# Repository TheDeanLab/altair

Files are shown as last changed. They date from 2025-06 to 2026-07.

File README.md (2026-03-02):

<h1 align="center">
altair

altair

<h3 align="center">
	Cost-Effective, Open-Source, Light-Sheet Microscopy Solutions for Subcellular Imaging.
</h3>
</h1>





**Altair** aims to democratize high-resolution light-sheet fluorescence microscopy. By combining **modular optomechanics**, **cutting-edge lens simulations**, and **intelligent software**, **Altair** enables the rapid assembly of high-performance light-sheet microscopes in a user-friendly package.

As reported in our eLife publication, Altair-LSFM is a high-resolution, sample-scanning light-sheet microscope that uses an in-silico optimized optical train and a custom-machined baseplate to simplify alignment. In bead-based benchmarking, Altair-LSFM achieved average FWHM values of 328 nm (x), 330 nm (y), and 464 nm (z) before deconvolution, improving to 235.5 nm (x), 233.5 nm (y), and 350.4 nm (z) after deconvolution across a 266 µm field of view.

## Publication

- Haug J, Galecki S, Lin H-Y, Wang X, Dean KM. *A high-resolution, easy-to-build light-sheet microscope for subcellular imaging.* eLife. 2025;14:RP106910. [https://doi.org/10.7554/eLife.106910](https://doi.org/10.7554/eLife.106910)

## Motivation

Cellular behavior is orchestrated by diverse signaling mechanisms that often hinge on **molecular events precisely organized in space and time**. These events include rapid, localized protein interactions that drive processes such as cell division, migration, and differentiation. **Altair** addresses the need for **high-resolution live-cell imaging**, empowering researchers to:

- Visualize spatially regulated processes.
- Collect quantitative 3D time-lapse data.
- Bridge molecular probe design and advanced computational image analysis.

## Goal

The overarching goal is to provide a **modular, cost-effective 3D light-sheet microscope** that:
- Can be assembled with minimal prior optics expertise.
- Delivers ~235 nm lateral and ~350 nm axial resolution after deconvolution (~328/330 nm in XY and ~464 nm in Z before deconvolution) across a 266 µm field of view.
- Seamlessly integrates with our user-friendly, **intelligent imaging software** [navigate](https://github.com/TheDeanLab/navigate).
- Streamlines data acquisition, drastically reducing barriers to cutting-edge microscopy.

## Key Features

1. **High-Resolution Optics**  
   - Optical designs extensively **simulated in Ansys Zemax OpticStudio** to ensure robust performance across the visible spectrum.
   - Thorough **tolerance analysis** to maintain alignment and resolution in non-specialist environments.

2. **Rugged Mechanical Design**  
   - **Computer-aided design (CAD) with Autodesk Inventor** for stress testing and mechanical reliability.
   - **Xometry** manufacturing ensures precision component fabrication.
   - **Dowel pins** and **Thorlabs Polaris mounts** allow reproducible alignment of optical elements.

3. **Easy-to-Source Components**  
   - Optics primarily sourced from **Thorlabs**, with **Polaris mounts** for stable positioning.
   - Motion control solutions (X, Y, Z, focus, sample scanning) from **Applied Scientific Instrumentation**.
   - Open-hardware ethos with minimal custom parts to reduce cost and wait times.
   - Detailed step-by-step assembly instructions.

4. **Intuitive Control Software**  
   - Built to interface seamlessly with [navigate](https://github.com/TheDeanLab/navigate).
   - Automated routines for calibration, 3D volume acquisition, and intelligent imaging.

## Getting Started

- **Review the [Documentation](https://thedeanlab.github.io/altair/)**
- **Procure Hardware**
- **Download and Install** [navigate](https://github.com/TheDeanLab/navigate)
- **Assemble Hardware**
- **Optimize Alignment**
- **Validate Performance**

## Authors

- John Haug, Ph.D.
- Kevin M. Dean, Ph.D.

## Funding

- **UTSW-UNC Center for Cell Signaling Analysis** NIH NIGMS RM1GM145399
- **Center for Metastatic Tumor Imaging** NIH NCI U54CA268072

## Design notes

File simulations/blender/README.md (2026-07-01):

# Blender Optics Simulations

This directory contains Blender Python source for educational Altair optics
alignment videos.

The scripts build Blender scenes programmatically. The Python source is the
source of truth; generated `.blend` files and rendered movies are build
artifacts.

## First Scene

`scenes/achromat_back_reflection.py` generates a teaching scene for aligning a
mounted achromatic doublet with a narrow collimated 561 nm laser beam. The beam
passes through a small aperture in a business card, reaches the lens, and two
back-reflection spots return to the card. The animation shows separate
ray-traced alignment states: rotation correction moves both spots together,
horizontal translation splits and recenters the spots left/right, vertical
translation splits and recenters the spots up/down, and final alignment centers
both return spots on the aperture.

The model is intentionally hybrid: it is geometrically plausible and uses
teaching-scale dimensions, but it exaggerates small alignment errors so the
motion is legible in video. The lens is represented as an AC254-100-A-style
cemented doublet with separate N-BK7 and SF5 elements, a curved cemented
interface, a weakly curved rear surface, and an LMR1-style fixed mount. Return
spots are computed from geometric ray-bundle reflections and therefore have
surface-dependent positions and diameters.

The scene includes three camera views: a wide setup view, a close-up view of the
card aperture and return spots, and a slow hero camera move for a polished
single-view movie. Minimal in-scene labels identify the aperture card, doublet,
mount, and two return reflections without adding narration or external editing.

## Walking-Beam Scene

`scenes/walking_beam_alignment.py` generates a teaching scene for walking a
laser beam with two steering mirrors and two irises. The scene uses an
import-safe finite-aperture ray trace from the source through M1, M2, Iris 1,
and Iris 2. Beam segments, mirror footprints, iris spots, blocking/clipping
state, and mirror display rotations are derived from that trace.
Animated beam segments are rendered as endpoint-keyframed curve objects, not
Euler-rotated cylinders, so the visible beam remains constrained by the traced
start and end points between storyboard samples.

The tutorial sequence starts misaligned, uses M1 to center the near iris, uses
M2 to center the far iris, then alternates through two refinements until both
irises are centered. Rendered views include wide, iris close-up, hero, top-down,
and stacked diagnostics. The top-down view is particularly useful for checking
that the folded M1-to-M2 path is continuous and that the post-M2 direction is
unambiguous.

## Fidelity Notes

`altair_blender/prescriptions.py` stores the source-backed model constants. The
mounted AC254-100-A-ML dimensions and LMR1/M mount dimensions come from Thorlabs
drawings. The AC-series surface prescription is used for the educational
geometric model so the rendered doublet and reflected spots respond to surface
curvature.

The spot animation traces reflected ray bundles from selected spherical
surfaces back to the card plane. The optics helpers also include a sequential
geometric tracer that branches rays into reflected and transmitted paths through
all modeled achromat surfaces. The model does not yet include wavelength-
dependent coating reflectance, polarization, diffraction at the aperture, or
Gaussian beam propagation. Spot positions and diameters are physically
motivated, then visually scaled for legibility.

## Run

From the repository root:

```bash
blender --background --python simulations/blender/scenes/achromat_back_reflection.py
```

To save a generated Blender file, pass a path after `--`:

```bash
blender --background --python simulations/blender/scenes/achromat_back_reflection.py -- output/achromat_back_reflection.blend
```

The output directory must already exist.

## Render Movies

Use the render script to create the `.blend` file, wide/card/hero PNG
sequences, wide/card/hero MP4 movies, a vertically stacked wide-plus-card PNG
sequence, and a stacked MP4 movie:

```bash
simulations/blender/scripts/render_achromat_back_reflection.sh
```

The default render mode is `final`, which applies the Cycles beauty preset. Use
`--draft` for fast card-only timing checks, or `--preview` /
`RENDER_MODE=preview` for full-pipeline EEVEE iteration.

For a fast draft render that only writes the card close-up movie at lower
resolution with frame stepping:

```bash
simulations/blender/scripts/render_achromat_back_reflection.sh --draft output/draft
```

By default, outputs are written under `output/achromat_back_reflection/`:

```text
achromat_back_reflection.blend
frames/wide/frame_0001.png ...
frames/card_closeup/frame_0001.png ...
frames/hero/frame_0001.png ...
frames/stacked/frame_0001.png ...
achromat_back_reflection_wide.mp4
achromat_back_reflection_card_closeup.mp4
achromat_back_reflection_hero.mp4
achromat_back_reflection_stacked.mp4
```

For a faster smoke render, override the frame range and resolution:

```bash
FRAME_START=1 FRAME_END=24 RESOLUTION_X=960 RESOLUTION_Y=540 \
  simulations/blender/scripts/render_achromat_back_reflection.sh --preview output/smoke
```

Run a dry-run plan without invoking Blender or `ffmpeg`:

```bash
simulations/blender/scripts/render_achromat_back_reflection.sh --dry-run
simulations/blender/scripts/render_achromat_back_reflection.sh --draft --dry-run
simulations/blender/scripts/render_achromat_back_reflection.sh --preview --dry-run
```

Render the walking-beam scene with:

```bash
simulations/blender/scripts/render_walking_beam_alignment.sh
```

For key-frame still review:

```bash
simulations/blender/scripts/render_walking_beam_alignment_stills.sh --draft --frame 72 output/walking-beam-frame-72
```

## Test

Run non-Blender checks from the repository root:

```bash
uv run pytest tests/test_blender_optics_math.py tests/test_blender_import_contracts.py tests/test_blender_endpoint_beams.py tests/test_achromat_scene_contract.py tests/test_blender_render_script.py tests/test_walking_beam_physics.py tests/test_walking_beam_scene_contract.py tests/test_walking_beam_render_script.py
```

If `uv run` is not suitable in the local environment, use:

```bash
pytest tests/test_blender_optics_math.py tests/test_blender_import_contracts.py tests/test_blender_endpoint_beams.py tests/test_achromat_scene_contract.py tests/test_blender_render_script.py tests/test_walking_beam_physics.py tests/test_walking_beam_scene_contract.py tests/test_walking_beam_render_script.py
```

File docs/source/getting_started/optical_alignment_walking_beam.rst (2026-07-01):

.. _optical_alignment_walking_beam:

#################################
Walking A Beam Through Two Irises
#################################

Goal
====

The goal is to make a laser beam pass through the centers of two same-height
irises after two steering mirrors. The first iris defines the near point on the
desired optical axis. The second iris defines the far point. When the beam is
centered on both irises, the beam position and angle match the line selected by
those two apertures.

This is a geometric alignment method. It does not require the downstream optic
to be installed yet, which makes it useful when setting beam height, preparing a
beam expander path, or establishing a clean reference line across an optical
table.

.. card:: Walking-Beam Alignment Simulation

   This simulation shows a Z-fold made from two kinematic mirror mounts and two
   same-height irises on a 25.4 mm table-hole row. The wide view shows the two
   mirrors walking the beam onto the iris row. The close-up view shows the near
   and far iris readouts during each correction. The top-down panel shows why
   the method controls both lateral beam position and propagation angle.

   .. raw:: html

      <video controls preload="metadata" style="width:100%;">
        <source src="../_static/optical_alignment/videos/walking_beam_alignment_stacked.mp4" type="video/mp4">
        Your browser does not support embedded video.
      </video>

   `Download the walking-beam alignment movie <../_static/optical_alignment/videos/walking_beam_alignment_stacked.mp4>`_

   The top-down view is useful when checking whether the beam path remains
   continuous from mirror to mirror and then through both irises.

   .. raw:: html

      <video controls preload="metadata" style="width:100%;">
        <source src="../_static/optical_alignment/videos/walking_beam_alignment_top_down.mp4" type="video/mp4">
        Your browser does not support embedded video.
      </video>

   `Download the top-down walking-beam movie <../_static/optical_alignment/videos/walking_beam_alignment_top_down.mp4>`_

Why This Works
==============

A straight beam is fully specified by two points. Two irises therefore define
the desired path: the beam must pass through the first aperture and then through
the second aperture without clipping.

The two mirrors provide two coupled controls. A first-mirror adjustment changes
where the beam lands at the near iris and also changes the downstream angle. A
second-mirror adjustment changes the downstream angle and therefore moves the
far iris spot strongly. Because the controls are coupled, a single pass is
rarely perfect. Alternating between the near iris and the far iris converges on
the line through both aperture centers.

Use small iris openings only after rough alignment is close. Starting with a
larger opening prevents accidental clipping and makes it easier to see which
mirror adjustment is moving the beam in the intended direction.

Setup Geometry
==============

Use a low-power visible alignment beam, wear appropriate laser safety eyewear,
and place beam blocks wherever the rough beam or mirror reflections could leave
the intended table path.

Place Iris 1 as close as reasonably possible to the second steering mirror. This
near iris gives a sensitive readout of the beam position just after the mirror
pair. Place Iris 2 farther downstream on the same desired path. A longer
distance between the two irises makes angular error easier to see, so the final
alignment is more accurate when the far iris is placed farther away.

A table-hole row is a convenient reference for a straight horizontal path. When
using the holes as a geometric reference, place each mirror so that the mirror
surface is centered on the intended turning point of the hole pattern. The
outside of the mirror mount is not the optical reference; the reflective surface
is.

Before beginning, set the mirror actuators near the middle of their travel.
This leaves adjustment range in both directions. Also center the beam on both
mirror surfaces during rough placement. If the beam starts near an edge of a
mirror, later corrections can clip the beam or force the actuator to the end of
its range.

Right-angle reflections are convenient because they make the geometry easy to
read on a rectangular optical table, but they are not required. Two steering
mirrors are sufficient to laterally translate a beam onto a new parallel path.

Step-By-Step Protocol
=====================

1. Set both irises to the same height and place them on the desired beam path.
   Put Iris 1 close to Mirror 2 and Iris 2 farther downstream on the same
   reference line.

2. Open both irises enough that the rough beam can be found safely without
   clipping.

3. Place two steering mirrors before the first iris. Start with the mirror
   actuators near mid-travel, the beam centered on both mirror faces, and the
   reflective surfaces located on the intended table-hole turning points.

4. Roughly steer the beam so that it reaches the first iris and continues toward
   the second iris.

5. Adjust the first mirror to center the near iris. Watch the beam spot at
   Iris 1 and use small, deliberate mirror motions.

6. Adjust the second mirror to center the far iris. Watch the beam spot at
   Iris 2 and bring it to the same-height aperture center.

7. Return to the first mirror and re-center Iris 1. The second-mirror change
   usually perturbs the near iris slightly.

8. Return to the second mirror and re-center Iris 2.

9. Iterate until both iris spots stay centered after each correction.

10. Reduce the iris openings and repeat the final corrections. Stop when the
    beam passes cleanly through both apertures at the working aperture size.

Troubleshooting
===============

If Iris 1 centers but Iris 2 moves far away, the mirror corrections are too
large or the initial Z-fold geometry is too coarse. Open the far iris, make a
rough second-mirror correction, and then restart with smaller movements.

If Iris 2 centers but Iris 1 no longer transmits, return to the first mirror.
This is the normal coupling between the two controls, not a sign that the
method failed.

If the beam clips both irises at different heights, recheck the mechanical
height of the iris centers before continuing. Walking the beam cannot fix a
reference line defined by apertures at different heights.

If the beam shape changes or becomes crescent-shaped at an iris, the beam is
clipping. Open the iris, recover a full round spot, and only then close the
aperture again.

If a mirror actuator runs out of range, do not keep forcing the correction with
the knob. Recenter the actuator, reposition the mirror mount so the beam is
again near the center of the mirror, and restart the rough alignment.

If the beam is centered on both irises but walks across a mirror surface, the
mechanical layout is probably not centered on the intended turning points. Move
the mount so the reflective surface, not the mount body, coincides with the
reference geometry, then repeat the alignment.

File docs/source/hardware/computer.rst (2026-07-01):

.. _computer-home:

###############################
Acquisition Computer
###############################

Modern scientific cameras are capable of capturing images at very high frame rates.
For example, the Orca-Lightning from Hamamatsu, when imaging a region of interest of
4608 × 128, can image at 2203 frames per second, totaling 1.3 terapixels per second. It
is important to have a computer that can handle this data rate. For many applications, we recommend Colfax International's SXP9000 workstation, which
includes several convenient features, including:

-   A large number of high-speed peripheral slots. While originally designed to host
    GPU cards, these slots can be used for other high-speed peripherals, such as frame
    grabbers.
-   A high-speed NVMe SSD, which can achieve upwards of 20 GB/s under ideal
    conditions.
-   10 GbE LAN - 10 G Ethernet or faster, if supported by your institution, is highly
    recommended for transferring data to and from the computer. This computer provides
    this high-speed connection without necessitating an additional network card, freeing
    up precious space in the computer.
-   USB-C ports that can be used for image display, keyboard, and mouse. Again, by
    eliminating the need for a graphics card, more space is available to other
    peripheral devices.
-   Redundant power supplies - in the event of a power supply failure, the computer will
    continue to operate. Moreover, they will be able to drive some of the more power-hungry
    components, such as frame grabbers.
-   Aggressive cooling - the computer is designed to handle the heat generated by the
    high-speed components.

---------------

Standard Specifications
_______________________

A general build for an imaging computer is as follows:

-   Windows 10 Pro. This is the most common operating system for scientific imaging
    applications.
-   2 × Intel Xeon Silver CPUs, for a total of 16 cores/32 threads at 3.2 GHz. Higher speeds
    and a greater number of cores are advantageous but expensive.
-   128 GB of 3200 MHz DDR4 RAM. This is more than sufficient for most applications.
-   800 GB M.2 NVMe SSD. Used to host and run the operating system.
-   20 TB 7200 RPM SATA HDD. Used as a 'cold storage' for long-term data storage.
-   NVIDIA T1000 Video Card. This is a low-end video card that can be used to drive
    displays and perform some basic image processing. The priority for this computer
    is driving the microscope and acquiring data, so a high-end video card is not necessary.
-   Intel X710-T2L 10 GbE card. If the motherboard does not provide 10 GbE, this card can
    be used to provide high-speed network connectivity.
-   7.68 TB NVMe SSD. Used as the primary data drive.

.. note::

    Recently, Hamamatsu released a Linux driver for their cameras. Linux
    provides several advantages to Windows-based operating systems, including read
    and write operations with lower overhead. This is especially important for next-generation
    file formats, such as N5, OME-Zarr, and Zarr, all of which break large
    images up into smaller 'chunks' that can be read and written independently. To
    learn more, we recommend reading
    `Moore et al. 2021 <https://pubmed.ncbi.nlm.nih.gov/34845388/>`_, and
    `Moore et al. 2023 <https://pubmed.ncbi.nlm.nih.gov/37428210/>`_.

-------------

Configuring Power Management Settings
_____________________________________

On modern platforms, the *computer's* power management configuration (Windows power plan, chipset/firmware drivers, and BIOS/UEFI power features) can materially affect throughput, latency, and run-to-run stability. By properly configuring the computer, navigate will operate more deterministically and at higher performance. Below is a step-by-step guide to optimize these settings.

Protocol: Windows configuration
------------------------------------

1. Update baseline software and firmware
^^^^^^^^^^^^^^^^^^^^^^^^^^^^^^^^^^^^^^^^

#. Ensure the system is on a supported Windows release (Windows 10/11 or Windows Server).
#. Apply your vendor's recommended BIOS/BMC/firmware updates (Supermicro/HPE/Dell/etc.).
#. Reboot after firmware updates.

2. Set Windows to a performance-focused power mode
^^^^^^^^^^^^^^^^^^^^^^^^^^^^^^^^^^^^^^^^^^^^^^^^^^

**General Power Settings** - We recommend setting Windows to a performance-oriented power plan to minimize power-saving features that can impact performance. This includes the high performance plan or, where available, the ultimate performance plan. To change these settings via the GUI, navigate to:
Control Panel → Power Options → select **High performance** (or **Ultimate Performance**).

**Minimum Processor Settings** - Additionally, adjust the processor power management settings to ensure the CPU operates at full performance when plugged in. Set both the minimum and maximum processor states to 100% and disable PCI Express Link State Power Management. This can be done via:
Control Panel → Power Options → Change plan settings → Advanced power settings:

3. Install chipset platform drivers (including Intel Management Engine)
^^^^^^^^^^^^^^^^^^^^^^^^^^^^^^^^^^^^^^^^^^^^^^^^^^^^^^^^^^^^^^^^^^^^^^^

The Intel Management Engine (ME) provides platform management
capabilities independent of the OS. Install the latest ME drivers from your
motherboard or system vendor's support page.

#. Install your **vendor chipset driver bundle** (preferred for servers/workstations).
#. Install the **Intel Management Engine Interface (MEI)** driver package (vendor-supplied).
#. Reboot.

**Confirm MEI is installed:**
Device Manager → System devices → look for **Intel(R) Management Engine Interface**.

4. Optional Windows Update: CPU/chipset-related driver updates
^^^^^^^^^^^^^^^^^^^^^^^^^^^^^^^^^^^^^^^^^^^^^^^^^^^^^^^^^^^^^^

Windows can deliver additional driver updates through **Optional updates**.

Settings → Windows Update → Advanced options → Optional updates → Driver updates

Protocol: BIOS/UEFI configuration
---------------------------------

The exact BIOS menu paths vary by vendor and CPU generation, but the concepts are consistent.

1. NUMA and Node Interleaving
^^^^^^^^^^^^^^^^^^^^^^^^^^^^^

* **Disable Node Interleaving** (recommended for modern NUMA-aware OSes).
  When enabled, firmware interleaves memory across sockets and presents a UMA-like view,
  which typically reduces NUMA locality benefits.

.. important::
   Some platforms do not expose an explicit **Node Interleaving** toggle (or it is hidden
   when the platform defaults to NUMA mode). In that case, verify NUMA is active in the OS
   (multiple NUMA nodes visible) and proceed with the remaining power settings.

2. Power and idle-state controls (C-states, P-states)
^^^^^^^^^^^^^^^^^^^^^^^^^^^^^^^^^^^^^^^^^^^^^^^^^^^^^

These settings are commonly found under:

Advanced → Advanced CPU Configuration → Advanced Power Management Configuration

The intent is:

* Keep **Turbo + P-states enabled** (fast frequency scaling).
* Disable **deep core/package C-states** (avoid wake-up latency and jitter).
* Disable **autonomous hardware power management** (keep behavior deterministic).

Recommended BIOS settings (with 1-line descriptions)
----------------------------------------------------

.. list-table:: BIOS settings reference (performance mode)
   :header-rows: 1
   :widths: 28 18 54

   * - Setting (location)
     - Recommended
     - What it does (1 line)
   * - **CPU P State Control** (APM)
     -
     -
   * - AVX P1
     - Nominal
     - Controls the target performance state under heavy AVX; *Nominal* avoids extra down-binning beyond platform defaults.
   * - SpeedStep (P-states)
     - Enabled
     - Enables OS-managed frequency/voltage scaling (fast ramp-up without sleeping).
   * - EIST PSD Function
     - HW_ALL
     - Uses hardware assistance for P-state transitions across all cores for responsiveness.
   * - Turbo Mode
     - Enabled
     - Allows boosting above base frequency when power/thermals permit.
   * - **Hardware PM State Control** (APM)
     -
     -
   * - Hardware P-States (HWP)
     - Disabled
     - Prevents the CPU from autonomously selecting performance states (keeps policy deterministic).
   * - Autonomous PM
     - Disabled
     - Disables out-of-band autonomous power decisions that can introduce variability.
   * - **CPU C State Control** (APM)
     -
     -
   * - Enable Monitor MWAIT
     - Disabled
     - Disables MWAIT-based idle entry hints that can lead to deeper idle behavior.
   * - CPU C1 Auto Demotion
     - Disabled
     - Prevents automatic demotion from shallow idle (C1) into deeper C-states.
   * - CPU C6 Report
     - Disabled
     - Hides C6 from the OS, preventing deep core sleep selection.
   * - Enhanced Halt State (C1E)
     - Disabled
     - Disables C1E voltage/frequency drop behavior that can add wake latency/jitter.
   * - **Package C State Control** (APM)
     -
     -
   * - Package C State
     - Disabled
     - Prevents the entire socket/package from entering deep idle (high wake latency).
   * - Package C State Limit
     - C0/C1
     - Caps package idle to shallow states only (best for consistent multi-socket performance).

References
----------

* `Microsoft powercfg documentation <https://learn.microsoft.com/en-us/windows-hardware/design/device-experiences/powercfg-command-line-options>`_
* `Recommended hardware drivers <https://support.microsoft.com/en-us/windows/automatically-get-recommended-and-updated-hardware-drivers-0549a8d9-4842-8acb-75fa-a6faadb62507>`_
* `Windows power and performance tuning <https://learn.microsoft.com/en-us/windows-server/administration/performance-tuning/hardware/power/power-performance-tuning>`_
* `Understanding automatic and optional updates <https://learn.microsoft.com/en-us/windows-hardware/drivers/dashboard/understanding-windows-update-automatic-and-optional-rules-for-driver-distribution>`_
* Intel Management Engine resources (vendor support pages)
* `C-state guidance - Part 1 <https://edc.intel.com/content/www/us/en/design/products/ethernet/appnote-perf-tuning-guide-700-series-linux/%E2%80%8Bc-state-control/>`_
* Cisco UCS BIOS tuning guides (vendor support pages)

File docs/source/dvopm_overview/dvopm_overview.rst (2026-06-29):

.. _dvopmoverview-home:

##############################
Introduction
##############################

Direct-View OPM
_______________

Direct-View Oblique Plane Microscopy (dvOPM) is an oblique-plane light-sheet microscopy technique designed for mesoscopic fluorescence imaging of extended specimens. In this approach, an oblique imaging plane within the sample is optically sectioned using a light sheet and directly projected onto a camera sensor.

Conventional oblique-plane microscopy systems typically rely on a tertiary imaging objective to re-image the tilted plane onto the detector. In contrast, dvOPM eliminates this requirement by forming the remote image directly on the camera sensor using a simplified relay. This reduces optical complexity and system footprint while preserving the optical sectioning capability of light-sheet microscopy.

As a result, dvOPM enables imaging over large fields of view with optical sectioning in a compact and accessible optical configuration.

------------------------------

System Architecture
___________________

A typical dvOPM system consists of separate illumination and detection optical paths arranged around a shared sample region. The illumination path generates an oblique light sheet that intersects the specimen, while the detection path collects fluorescence from the illuminated plane and relays the tilted image onto a camera sensor.

In general implementations, the detection path is formed using microscope objectives and relay optics, often requiring multiple objectives to re-image the oblique plane. The illumination path is typically implemented separately from the detection optics, particularly when using low numerical aperture objectives that do not support integrated light-sheet delivery. The system is commonly operated in a stage-scanning configuration, where the sample is translated through the stationary illumination and detection planes to acquire volumetric data.

The Altair dvOPM presented here follows this overall architecture while implementing a specific realization of the system as described below.

The detection subsystem is implemented as a remote-imaging relay using a pair of photographic lenses with external pupils. An emission filter wheel (FW1000, Applied Scientific Instrumentation) is positioned within the relay to enable fluorescence imaging. The image is formed directly onto a compact camera (Ximea MU196MR-ON) with a pixel size of 1.4 µm. The entire detection assembly is mounted on a modular baseplate and attached to a motorized linear translation stage, allowing the detection train to be positioned relative to the specimen.

The illumination subsystem is implemented as a separate optical train. It begins with a Powell lens, followed by a sequence of three achromatic doublets that relay and shape the beam. A resonant galvo is incorporated within the illumination path, and the resulting beam forms a micron-scale light sheet that is launched obliquely into the specimen.

The system operates in a stage-scanning geometry, where the sample is translated through the stationary illumination and detection planes. The illumination and detection subsystems are mounted as independent modular baseplates on the optical table, while the stage is positioned above them.

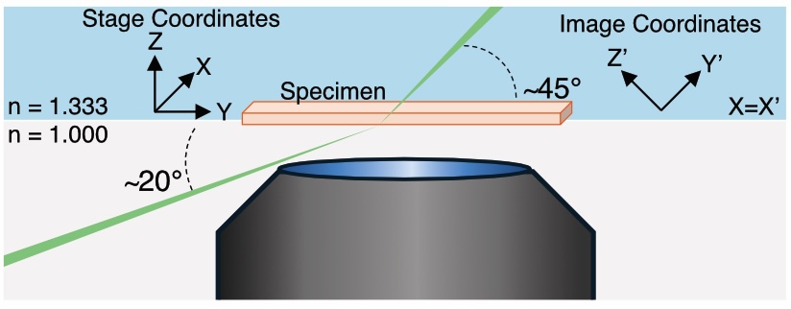
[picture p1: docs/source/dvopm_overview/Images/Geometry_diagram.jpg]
Schematic of the Altair DV-OPM system.


    **Figure 1:** Schematic Geometry of the Altair DV-OPM system. 

The above the schematic illustrates the optical geometry of the system, showing the relative arrangement of the illumination and detection paths around the sample region and the axes defining the oblqiue plane and the stage coordinates.
The illumination light-sheet is launched externally through the coverslip at an angle of approximately 20◦ and refracts to approximately 45◦ upon entering the aqueous specimen. Fluorescence from the obliquely illuminated plane is collected in the epi-direction by the photographic-lens-based detection path. Unprimed axes denote the stage coordinate system, in which Y is the sample-scanning direction, Z is the specimen-depth direction and X is parallel to the long axis of the light-sheet. Primed axes denote the oblique image coordinate system recorded by the camera, in which Y′ is the light-sheet propagation direction, X′ is the long
axis of the light-sheet and Z′ defines the light-sheet thickness. The stage X axis corresponds to the image X′ axis. Thus, each camera frame captures an X′Y′ oblique plane, while volumetric imaging is performed by translating the specimen along stage Y . Following acquisition, image stacks are computationally sheared and rotated into the stage coordinate frame for visualization. 

------------------------------

The detailed optical design and implementation of the detection and illumination subsystems are described in the following section.

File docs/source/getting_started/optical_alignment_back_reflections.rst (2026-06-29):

.. _optical_alignment_back_reflections:

#########################
Back-Reflection Alignment
#########################

The goal is to make the optic normal to the incoming beam and centered on the
beam path. A simple aperture card lets you see light that reflects from the
optic and returns toward the source. When the useful back-reflection spots are
centered on the aperture, the optic is close to normal incidence and centered
well enough to continue the alignment.

This method is useful because it gives a fast, sensitive readout before moving
to more complicated system-specific alignment steps. It does not replace later
checks of beam height, beam walk, collimation, or image quality, but it helps
establish a clean starting condition for each optic.

.. card:: Achromat Back-Reflection Simulation

   This simulation shows a collimated 561 nm alignment beam passing through a
   small aperture in a card, reflecting from an achromatic doublet, and returning
   two spots to the card. The top view shows the physical layout. The lower view
   shows the aperture-card readout as tilt and position are corrected.

   .. raw:: html

      <video controls preload="metadata" style="width:100%;">
        <source src="../_static/baseplate2_alignment/alignment/videos/achromat_back_reflection_stacked.mp4" type="video/mp4">
        Your browser does not support embedded video.
      </video>

   `Download the alignment movie <../_static/baseplate2_alignment/alignment/videos/achromat_back_reflection_stacked.mp4>`_

Why This Works
==============

When a lens is placed in a laser beam, a small amount of light reflects from
each optical surface. For a simple lens or achromat, the most visible returns
often come from the front and rear surfaces. These returns appear as distinct
spots on the card.

Flat or nearly plano surfaces return a crisp, collimated spot that is roughly
the same diameter as the incoming alignment beam. Spherical or curved surfaces
can return spots that expand or focus, depending on the curvature of the surface
and the distance back to the card. In compound optics, the different surfaces
can therefore produce spots with different sizes.

The card gives those returns a visible target. The aperture marks the incident
beam position. If a return spot lands on the aperture, that reflected ray bundle
is traveling back along the incident beam path.

Setup
=====

Use a visible, low-power, collimated alignment beam. A 561 nm beam is convenient
when it is available, but the same geometry applies to other visible alignment
wavelengths. Keep the beam power low, use proper laser safety practices, and
avoid looking directly into any specular reflection.

Place a target card with a small aperture in the beam before the optic. A
business card with a narrow aperture works well because it blocks enough light
to reveal the return spots while still allowing the incident beam to pass. The
aperture must be centered on the true beam path before the optic is inserted.
If the aperture is not centered, the card itself biases the measurement.

Mount the optic downstream of the card. Keep enough space between the card and
optic for the return spots to separate visibly, but not so much space that weak
reflections become hard to see.

Interpreting The Reflection Spots
=================================

If the beam is not centered on the optic, the back reflections will be displaced
on the card. Lateral displacement of the optic moves the return spots laterally.
Vertical displacement also moves the return spots on the card because the card
records the beam position in its transverse plane.

When the beam is normal to the optic, the useful return spots should move in a
symmetrical way as the optic is centered. If the optic is tilted relative to the
laser propagation direction, the return spots will not be displaced
symmetrically. This asymmetry is the key sign that angle must be corrected
before position can be trusted.

The aperture card is part of the measurement. A shifted, tilted, damaged, or
poorly sized aperture can make a good optic alignment look bad, or make a bad
alignment look better than it is. Recheck the aperture position whenever the
beam path or card position changes.

Step-By-Step Protocol
=====================

1. Establish a clean, collimated alignment beam at the desired beam height.

2. Place the aperture card upstream of the optic location.

3. Center the aperture on the incident beam. The beam should pass cleanly
   through the aperture without clipping.

4. Insert the optic in its mount downstream of the card.

5. Observe the return spots on the card. For an achromat, expect more than one
   visible return, and expect the spots to have different diameters.

6. Correct angular alignment first. Adjust tip and tilt until the useful return
   spots move symmetrically toward the aperture.

7. Correct lateral and vertical position. Translate the optic until the useful
   return spots are centered on the aperture.

8. Iterate angle and position adjustments. These degrees of freedom are coupled,
   so one pass is rarely enough.

9. Confirm the alignment. Translate the card slightly along the beam path and
   confirm that the useful return spots remain consistent with a centered,
   normal optic.

10. Continue to the next optic or to the system-specific alignment step.

Complex Optics
==============

Objectives and other multi-element assemblies can produce many back reflections.
Do not try to center every faint ghost reflection. Instead, identify the
reflections that are meaningful for the alignment step and use those returns
consistently.

The general principle remains the same: when the optic is centered and normal
to the beam, the useful return spots should come back toward the aperture in a
predictable and symmetric way. The more complicated the optic, the more
important it is to document which reflections are being used as the alignment
reference.

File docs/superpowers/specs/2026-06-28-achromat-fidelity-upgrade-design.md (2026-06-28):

# Achromat Fidelity Upgrade Design

## Goal

Increase the first Blender optics alignment simulation from a coarse teaching
approximation to a more physically plausible geometric visualization. The
scene should show an AC254-100-A-style cemented achromatic doublet in an
LMR1-style fixed mount, compute return spots from reflected ray bundles, show
different apparent reflection diameters, and render with shadows.

## Source Hierarchy

Use source data in this order:

1. Official Thorlabs AC254-100-A-ML mounted drawing for mounted lens and coating
   dimensions:
   `https://media.thorlabs.com/globalassets/items/a/ac/ac2/ac254-100-a-ml/20592-e0w.pdf?v=0116101917`
2. Official Thorlabs LMR1/M drawing for fixed mount dimensions:
   `https://thin01mstroc282prod.dxcloud.episerver.net/globalassets/items/l/lm/lmr/lmr1_m/0002-e0w.pdf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`
3. AC-series prescription values for the unmounted AC254-100-A optical surfaces
   when needed for ray tracing and mesh generation. Record these as prescription
   values, not manufacturing authority.

## Optical Model

The upgraded model uses an explicit prescription object for an AC254-100-A-like
doublet:

- lens diameter: 25.4 mm
- clear aperture: 90% of lens diameter
- effective focal length: about 100 mm
- back focal length: about 97 mm
- surfaces:
  - front convex spherical surface, N-BK7 side
  - cemented internal spherical interface between N-BK7 and SF5
  - weakly curved rear SF5 surface, visually close to flat
- center thicknesses:
  - first element: 4.0 mm
  - second element: 2.5 mm

The visual mesh should use the prescription surfaces directly enough that the
profile reads as a cemented doublet, while remaining robust and lightweight for
Blender rendering.

## Ray Model

The model traces a narrow collimated bundle from the card aperture to selected
reflective surfaces. For each surface, it:

- intersects each ray with the spherical surface;
- computes the local surface normal;
- reflects the incoming ray about that normal;
- intersects the reflected ray with the business-card plane;
- returns a spot center and diameter from the reflected bundle footprint.

The scene should use the most visually useful two reflections for the teaching
goal, while keeping the ray helper capable of handling additional surfaces.
The returned spots should generally have different diameters because different
surface curvature and effective reflection plane positions change the returned
bundle footprint.

## Scene And Rendering

Replace the cylinder lens with two transparent bonded glass elements and a
visible internal interface. Replace the torus mount with an LMR1-style fixed
mount: rectangular black-anodized body, central bore, retaining ring, spanner
slots, mounting base/post features, and clear aperture. Enable Blender shadows
with area lighting so the mount, card, and optical table feel grounded.

The existing render script remains the user-facing path. The fidelity upgrade
must preserve the wide, card close-up, and stacked movie outputs.

## Testing

Add non-Blender tests for:

- prescription constants and derived clear aperture;
- spherical sag and surface-normal behavior;
- ray bundle reflection returning centered spots when aligned;
- tilt/decenter producing surface-dependent offsets and different spot
  diameters;
- import-safe scene defaults including the AC254/LMR1 source labels.

Keep Blender-specific behavior verified by a short background smoke render.

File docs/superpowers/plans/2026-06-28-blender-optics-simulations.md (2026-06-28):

# Blender Optics Simulations Implementation Plan

> **For agentic workers:** REQUIRED SUB-SKILL: Use superpowers:subagent-driven-development (recommended) or superpowers:executing-plans to implement this plan task-by-task. Steps use checkbox (`- [ ]`) syntax for tracking.

**Goal:** Build a reusable Blender Python simulation area and a first achromatic-doublet back-reflection scene generator for educational optics-alignment videos.

**Architecture:** Add a dedicated `simulations/blender/` area with a small import-safe helper package, `altair_blender`, and one scene script under `scenes/`. Keep quantitative alignment math in pure Python functions that can be tested without Blender, while Blender API calls live behind lazy `bpy` imports so normal repository tests can still run.

**Tech Stack:** Python 3.9+, Blender Python API (`bpy`), standard library `dataclasses` and `math`, pytest, ruff, Sphinx-compatible Markdown documentation.

---

## File Structure

Create or modify these files:

- Create: `simulations/blender/AGENTS.md`
  - Local agent context for the Blender simulation subproject.
- Create: `simulations/blender/README.md`
  - User-facing overview and run instructions.
- Create: `simulations/blender/altair_blender/__init__.py`
  - Package marker and public version string.
- Create: `simulations/blender/altair_blender/optics.py`
  - Pure alignment math plus Blender beam/spot helpers.
- Create: `simulations/blender/altair_blender/scene.py`
  - Lazy Blender import, scene reset, units, render settings, collections.
- Create: `simulations/blender/altair_blender/materials.py`
  - Lazy material creation helpers.
- Create: `simulations/blender/altair_blender/geometry.py`
  - Optical table, business card, aperture, lens, mount, and label geometry.
- Create: `simulations/blender/altair_blender/cameras.py`
  - Wide and card close-up camera creation.
- Create: `simulations/blender/altair_blender/animation.py`
  - Keyframe and interpolation helpers.
- Create: `simulations/blender/scenes/achromat_back_reflection.py`
  - First scene generator and default timeline.
- Create: `tests/test_blender_optics_math.py`
  - Tests for pure return-spot math and validation.
- Create: `tests/test_blender_import_contracts.py`
  - Tests that helper modules import without Blender and expose expected functions.
- Create: `tests/test_achromat_scene_contract.py`
  - Tests that the scene script is import-safe and defines expected parameters.

Do not add generated `.blend`, MP4, GIF, image, or cache files in this implementation.

## Task 1: Scaffold The Blender Simulation Area

**Files:**
- Create: `simulations/blender/AGENTS.md`
- Create: `simulations/blender/README.md`
- Create: `simulations/blender/altair_blender/__init__.py`
- Create directory: `simulations/blender/scenes/`

- [ ] **Step 1: Confirm the working tree before creating files**

Run:

```bash
git status --short
```

Expected: no output, or only changes already known to be part of this plan.

- [ ] **Step 2: Create the simulation directories**

Run:

```bash
mkdir -p simulations/blender/altair_blender simulations/blender/scenes
```

Expected: command exits with status 0.

- [ ] **Step 3: Add local agent context**

Create `simulations/blender/AGENTS.md` with:

````markdown
# Blender Simulation Agent Notes

This directory contains source-controlled Blender Python scene generators for
Altair educational optics-alignment videos.

## Source Of Truth

- Python scene scripts and helper modules are source of truth.
- Generated `.blend`, rendered video, image, cache, and temporary files are build
  artifacts and should not be committed unless a later task explicitly changes
  that policy.

## Coordinate Convention

- Use millimeters as the teaching-scale unit in Python parameters.
- In Blender scene coordinates, 1 Blender unit represents 1 millimeter unless a
  scene-specific script states otherwise.
- The incident laser propagates along positive X by default.
- The business card target is upstream of the lens.
- The card face lies approximately in the Y-Z plane.
- Card aperture and return-spot offsets are expressed as `(y_mm, z_mm)` on the
  card face.

## Modeling Boundary

- These scenes are educational geometric visualizations.
- They should be physically plausible, but they are not quantitative optical
  design solvers.
- Do not claim exact wave optics, exact Fresnel/refraction behavior, or exact
  Zemax equivalence unless a future implementation adds that machinery.
- Visual exaggeration is allowed when an explicit parameter documents it.

## Run Pattern

Run a scene from the repository root with Blender:

```bash
blender --background --python simulations/blender/scenes/achromat_back_reflection.py
```

If Blender is not on `PATH`, document that limitation and run the non-Blender
pytest checks.

## Code Style

- Keep modules import-safe without Blender. Import `bpy` lazily inside functions
  that need it.
- Put reusable helpers in `altair_blender/`.
- Put scene-specific timelines in `scenes/`.
- Prefer explicit names over clever abstractions.
- Keep visual approximation constants visible near the top of scene scripts.
````

- [ ] **Step 4: Add README**

Create `simulations/blender/README.md` with:

````markdown
# Blender Optics Simulations

This directory contains Blender Python source for educational Altair optics
alignment videos.

The scripts build Blender scenes programmatically. The Python source is the
source of truth; generated `.blend` files and rendered movies are build
artifacts.

## First Scene

`scenes/achromat_back_reflection.py` generates a teaching scene for aligning a
mounted achromatic doublet with a narrow collimated 561 nm laser beam. The beam
passes through a small aperture in a business card, reaches the lens, and two
back-reflection spots return to the card. The animation shows tilt correction
followed by decenter correction until both return spots are centered on the
aperture.

The model is intentionally hybrid: it is geometrically plausible and uses
teaching-scale dimensions, but it exaggerates small alignment errors so the
motion is legible in video.

## Run

From the repository root:

```bash
blender --background --python simulations/blender/scenes/achromat_back_reflection.py
```

To save a generated Blender file, pass a path after `--`:

```bash
blender --background --python simulations/blender/scenes/achromat_back_reflection.py -- output/achromat_back_reflection.blend
```

The output directory must already exist.

## Test

Run non-Blender checks from the repository root:

```bash
uv run pytest tests/test_blender_optics_math.py tests/test_blender_import_contracts.py tests/test_achromat_scene_contract.py
```

If `uv run` is not suitable in the local environment, use:

```bash
pytest tests/test_blender_optics_math.py tests/test_blender_import_contracts.py tests/test_achromat_scene_contract.py
```
````

- [ ] **Step 5: Add package marker**

Create `simulations/blender/altair_blender/__init__.py` with:

```python
"""Reusable Blender helpers for Altair educational optics simulations."""

__version__ = "0.1.0"
```

- [ ] **Step 6: Verify formatting-sensitive checks**

Run:

```bash
git diff --check
```

Expected: no output.

- [ ] **Step 7: Commit scaffold**

Run:

```bash
git add simulations/blender/AGENTS.md simulations/blender/README.md simulations/blender/altair_blender/__init__.py
git commit -m "feat: scaffold blender simulation area"
```

Expected: commit succeeds.

## Task 2: Add Pure Alignment Math With Tests

**Files:**
- Create: `simulations/blender/altair_blender/optics.py`
- Create: `tests/test_blender_optics_math.py`

- [ ] **Step 1: Write failing tests for return-spot math**

Create `tests/test_blender_optics_math.py` with:

```python
import math

import pytest

from simulations.blender.altair_blender.optics import (
    SpotOffset,
    compute_return_spots,
    validate_positive,
)

def test_compute_return_spots_zero_alignment_centers_both_spots():
    spot_a, spot_b = compute_return_spots(
        tilt_y_deg=0.0,
        tilt_z_deg=0.0,
        decenter_y_mm=0.0,
        decenter_z_mm=0.0,
        card_to_lens_mm=75.0,
        exaggeration=10.0,
    )

    assert spot_a == SpotOffset(y_mm=0.0, z_mm=0.0)
    assert spot_b == SpotOffset(y_mm=0.0, z_mm=0.0)

def test_compute_return_spots_tilt_creates_common_offset():
    spot_a, spot_b = compute_return_spots(
        tilt_y_deg=0.25,
        tilt_z_deg=-0.10,
        decenter_y_mm=0.0,
        decenter_z_mm=0.0,
        card_to_lens_mm=75.0,
        exaggeration=8.0,
    )

    assert spot_a.y_mm > 0
    assert spot_b.y_mm > spot_a.y_mm
    assert spot_a.z_mm < 0
    assert spot_b.z_mm < spot_a.z_mm

def test_compute_return_spots_decenter_splits_spots_oppositely():
    spot_a, spot_b = compute_return_spots(
        tilt_y_deg=0.0,
        tilt_z_deg=0.0,
        decenter_y_mm=0.20,
        decenter_z_mm=-0.10,
        card_to_lens_mm=75.0,
        exaggeration=6.0,
    )

    assert math.isclose(spot_a.y_mm, -spot_b.y_mm)
    assert math.isclose(spot_a.z_mm, -spot_b.z_mm)
    assert spot_a.y_mm > 0
    assert spot_b.y_mm < 0
    assert spot_a.z_mm < 0
    assert spot_b.z_mm > 0

@pytest.mark.parametrize(
    ("name", "value"),
    [
        ("beam_diameter_mm", 0.0),
        ("aperture_diameter_mm", -1.0),
    ],
)
def test_validate_positive_rejects_nonpositive_values(name, value):
    with pytest.raises(ValueError, match=name):
        validate_positive(name, value)

def test_compute_return_spots_rejects_nonpositive_distance_and_exaggeration():
    with pytest.raises(ValueError, match="card_to_lens_mm"):
        compute_return_spots(
            tilt_y_deg=0.0,
            tilt_z_deg=0.0,
            decenter_y_mm=0.0,
            decenter_z_mm=0.0,
            card_to_lens_mm=0.0,
            exaggeration=1.0,
        )

    with pytest.raises(ValueError, match="exaggeration"):
        compute_return_spots(
            tilt_y_deg=0.0,
            tilt_z_deg=0.0,
            decenter_y_mm=0.0,
            decenter_z_mm=0.0,
            card_to_lens_mm=75.0,
            exaggeration=0.0,
        )
```

- [ ] **Step 2: Run tests and verify they fail because the module is missing**

Run:

```bash
uv run pytest tests/test_blender_optics_math.py -q
```

Expected: FAIL with `ModuleNotFoundError` or `ImportError` for `simulations.blender.altair_blender.optics`.

- [ ] **Step 3: Implement pure optics math**

Create `simulations/blender/altair_blender/optics.py` with:

```python
"""Optics helpers for educational Blender alignment scenes.

The numerical helpers in this module are intentionally simple geometric teaching
models. They are not a replacement for optical design software.
"""

from __future__ import annotations

from dataclasses import dataclass
import math

@dataclass(frozen=True)
class SpotOffset:
    """Return-spot offset on the business card face, in millimeters."""

    y_mm: float
    z_mm: float

def validate_positive(name: str, value: float) -> None:
    """Raise a clear error when a physical size or scale is not positive."""

    if value <= 0:
        raise ValueError(f"{name} must be positive; got {value!r}")

def compute_return_spots(
    *,
    tilt_y_deg: float,
    tilt_z_deg: float,
    decenter_y_mm: float,
    decenter_z_mm: float,
    card_to_lens_mm: float,
    exaggeration: float,
    decenter_response: float = 1.0,
) -> tuple[SpotOffset, SpotOffset]:
    """Compute teaching-level return-spot offsets for two lens reflections.

    A lens tilt creates a common walk-off of both reflected spots. A lens
    decenter splits the two surface reflections in opposite directions. The two
    surfaces are given slightly different tilt sensitivity so the viewer can
    distinguish the two return spots during correction.
    """

    validate_positive("card_to_lens_mm", card_to_lens_mm)
    validate_positive("exaggeration", exaggeration)
    validate_positive("decenter_response", decenter_response)

    common_y = 2.0 * math.tan(math.radians(tilt_y_deg)) * card_to_lens_mm * exaggeration
    common_z = 2.0 * math.tan(math.radians(tilt_z_deg)) * card_to_lens_mm * exaggeration
    split_y = decenter_y_mm * decenter_response * exaggeration
    split_z = decenter_z_mm * decenter_response * exaggeration

    spot_a = SpotOffset(
        y_mm=(0.85 * common_y) + split_y,
        z_mm=(0.85 * common_z) + split_z,
    )
    spot_b = SpotOffset(
        y_mm=(1.15 * common_y) - split_y,
        z_mm=(1.15 * common_z) - split_z,
    )
    return spot_a, spot_b
```

- [ ] **Step 4: Run optics tests and verify they pass**

Run:

```bash
uv run pytest tests/test_blender_optics_math.py -q
```

Expected: `6 passed`.

- [ ] **Step 5: Run lint on the new files**

Run:

```bash
uv run ruff check simulations/blender/altair_blender/optics.py tests/test_blender_optics_math.py
```

Expected: `All checks passed!`

If `uv run ruff` is unavailable in the environment, run:

```bash
ruff check simulations/blender/altair_blender/optics.py tests/test_blender_optics_math.py
```

- [ ] **Step 6: Commit optics math**

Run:

```bash
git add simulations/blender/altair_blender/optics.py tests/test_blender_optics_math.py
git commit -m "feat: add blender optics alignment math"
```

Expected: commit succeeds.

## Task 3: Add Import-Safe Scene And Material Helpers

**Files:**
- Create: `simulations/blender/altair_blender/scene.py`
- Create: `simulations/blender/altair_blender/materials.py`
- Create: `tests/test_blender_import_contracts.py`

- [ ] **Step 1: Write failing import-contract tests**

Create `tests/test_blender_import_contracts.py` with:

```python
import importlib

import pytest

def test_scene_and_material_modules_import_without_blender():
    scene = importlib.import_module("simulations.blender.altair_blender.scene")
    materials = importlib.import_module("simulations.blender.altair_blender.materials")

    assert callable(scene.get_bpy)
    assert callable(scene.reset_scene)
    assert callable(scene.configure_scene)
    assert callable(scene.ensure_collection)
    assert callable(materials.create_materials)

def test_get_bpy_reports_clear_error_outside_blender():
    scene = importlib.import_module("simulations.blender.altair_blender.scene")

    with pytest.raises(RuntimeError, match="Blender"):
        scene.get_bpy()
```

- [ ] **Step 2: Run import-contract tests and verify they fail**

Run:

```bash
uv run pytest tests/test_blender_import_contracts.py -q
```

Expected: FAIL because `scene.py` and `materials.py` do not exist.

- [ ] **Step 3: Implement scene helpers**

Create `simulations/blender/altair_blender/scene.py` with:

```python
"""Scene-level helpers for Blender-generated optics simulations."""

from __future__ import annotations

from pathlib import Path
from types import ModuleType

def get_bpy() -> ModuleType:
    """Return Blender's `bpy` module or raise a clear runtime error."""

    try:
        import bpy  # type: ignore[import-not-found]
    except ModuleNotFoundError as exc:
        raise RuntimeError("This function must be run inside Blender with bpy available.") from exc
    return bpy

def reset_scene() -> None:
    """Delete existing objects so the generated scene is deterministic."""

    bpy = get_bpy()
    bpy.ops.object.select_all(action="SELECT")
    bpy.ops.object.delete()

def configure_scene(*, frame_start: int, frame_end: int, fps: int = 24) -> None:
    """Configure units, timeline, render defaults, and world background."""

    bpy = get_bpy()
    scene = bpy.context.scene
    scene.frame_start = frame_start
    scene.frame_end = frame_end
    scene.frame_set(frame_start)
    scene.render.fps = fps
    scene.render.resolution_x = 1920
    scene.render.resolution_y = 1080
    scene.unit_settings.system = "METRIC"
    scene.unit_settings.scale_length = 0.001
    scene.eevee.taa_render_samples = 64
    scene.world.color = (0.015, 0.018, 0.022)

def ensure_collection(name: str):
    """Return a named collection, creating and linking it when needed."""

    bpy = get_bpy()
    collection = bpy.data.collections.get(name)
    if collection is None:
        collection = bpy.data.collections.new(name)
        bpy.context.scene.collection.children.link(collection)
    return collection

def validate_output_path(output_path: str | None) -> Path | None:
    """Validate an optional `.blend` output path."""

    if output_path is None:
        return None

    path = Path(output_path).expanduser()
    if not path.parent.exists():
        raise ValueError(f"Output directory does not exist: {path.parent}")
    return path
```

- [ ] **Step 4: Implement material helpers**

Create `simulations/blender/altair_blender/materials.py` with:

```python
"""Reusable material helpers for Blender optics scenes."""

from __future__ import annotations

from .scene import get_bpy

def _material(name: str, color: tuple[float, float, float, float], *, emission: float = 0.0):
    bpy = get_bpy()
    material = bpy.data.materials.new(name)
    material.diffuse_color = color
    material.use_nodes = True
    bsdf = material.node_tree.nodes.get("Principled BSDF")
    if bsdf is not None:
        bsdf.inputs["Base Color"].default_value = color
        bsdf.inputs["Alpha"].default_value = color[3]
        if "Emission Color" in bsdf.inputs:
            bsdf.inputs["Emission Color"].default_value = color
        if "Emission Strength" in bsdf.inputs:
            bsdf.inputs["Emission Strength"].default_value = emission
    material.blend_method = "BLEND"
    return material

def create_materials() -> dict[str, object]:
    """Create the standard material palette for the simulation."""

    return {
        "table": _material("Optical Table Matte Black", (0.025, 0.028, 0.03, 1.0)),
        "metal": _material("Black Anodized Metal", (0.08, 0.085, 0.09, 1.0)),
        "card": _material("Business Card Stock", (0.92, 0.88, 0.78, 1.0)),
        "aperture": _material("Aperture Edge", (0.02, 0.02, 0.018, 1.0)),
        "glass": _material("Coated Achromat Glass", (0.55, 0.82, 0.95, 0.32)),
        "laser": _material("561 nm Laser Beam", (0.35, 1.0, 0.18, 0.65), emission=2.5),
        "spot_a": _material("Return Spot A", (0.45, 1.0, 0.22, 1.0), emission=3.0),
        "spot_b": _material("Return Spot B", (0.18, 0.85, 1.0, 1.0), emission=2.6),
        "label": _material("Subtle Label", (0.9, 0.95, 1.0, 1.0)),
    }
```

- [ ] **Step 5: Run import-contract tests and verify they pass**

Run:

```bash
uv run pytest tests/test_blender_import_contracts.py -q
```

Expected: `2 passed`.

- [ ] **Step 6: Run lint**

Run:

```bash
uv run ruff check simulations/blender/altair_blender/scene.py simulations/blender/altair_blender/materials.py tests/test_blender_import_contracts.py
```

Expected: `All checks passed!`

- [ ] **Step 7: Commit scene and material helpers**

Run:

```bash
git add simulations/blender/altair_blender/scene.py simulations/blender/altair_blender/materials.py tests/test_blender_import_contracts.py
git commit -m "feat: add blender scene and material helpers"
```

Expected: commit succeeds.

## Task 4: Add Geometry And Camera Helpers

**Files:**
- Create: `simulations/blender/altair_blender/geometry.py`
- Create: `simulations/blender/altair_blender/cameras.py`
- Modify: `tests/test_blender_import_contracts.py`

- [ ] **Step 1: Extend import-contract tests for geometry and cameras**

Modify `tests/test_blender_import_contracts.py` to:

```python
import importlib

import pytest

def test_core_modules_import_without_blender():
    scene = importlib.import_module("simulations.blender.altair_blender.scene")
    materials = importlib.import_module("simulations.blender.altair_blender.materials")
    geometry = importlib.import_module("simulations.blender.altair_blender.geometry")
    cameras = importlib.import_module("simulations.blender.altair_blender.cameras")

    assert callable(scene.get_bpy)
    assert callable(scene.reset_scene)
    assert callable(scene.configure_scene)
    assert callable(scene.ensure_collection)
    assert callable(materials.create_materials)
    assert callable(geometry.create_optical_table)
    assert callable(geometry.create_business_card)
    assert callable(geometry.create_achromat)
    assert callable(geometry.create_lens_mount)
    assert callable(cameras.create_wide_camera)
    assert callable(cameras.create_card_closeup_camera)

def test_get_bpy_reports_clear_error_outside_blender():
    scene = importlib.import_module("simulations.blender.altair_blender.scene")

    with pytest.raises(RuntimeError, match="Blender"):
        scene.get_bpy()
```

- [ ] **Step 2: Run tests and verify they fail because modules are missing**

Run:

```bash
uv run pytest tests/test_blender_import_contracts.py -q
```

Expected: FAIL because `geometry.py` and `cameras.py` do not exist.

- [ ] **Step 3: Implement geometry helpers**

Create `simulations/blender/altair_blender/geometry.py` with:

```python
"""Geometry builders for Blender optics alignment scenes."""

from __future__ import annotations

import math

from .scene import get_bpy

def _link_to_collection(obj, collection) -> None:
    for existing in obj.users_collection:
        existing.objects.unlink(obj)
    collection.objects.link(obj)

def create_optical_table(*, collection, materials: dict[str, object], length_mm: float = 220.0, width_mm: float = 90.0):
    bpy = get_bpy()
    bpy.ops.mesh.primitive_cube_add(size=1, location=(70.0, 0.0, -8.0))
    table = bpy.context.object
    table.name = "Optical Table"
    table.dimensions = (length_mm, width_mm, 6.0)
    table.data.materials.append(materials["table"])
    _link_to_collection(table, collection)
    return table

def create_business_card(
    *,
    collection,
    materials: dict[str, object],
    x_mm: float,
    width_mm: float,
    height_mm: float,
    aperture_diameter_mm: float,
):
    bpy = get_bpy()
    bpy.ops.mesh.primitive_cube_add(size=1, location=(x_mm, 0.0, 15.0))
    card = bpy.context.object
    card.name = "Business Card Target"
    card.dimensions = (1.2, width_mm, height_mm)
    card.data.materials.append(materials["card"])
    _link_to_collection(card, collection)

    bpy.ops.mesh.primitive_torus_add(
        major_radius=aperture_diameter_mm * 0.72,
        minor_radius=0.08,
        major_segments=48,
        minor_segments=8,
        location=(x_mm - 0.7, 0.0, 15.0),
        rotation=(0.0, math.radians(90.0), 0.0),
    )
    aperture = bpy.context.object
    aperture.name = "Card Aperture"
    aperture.data.materials.append(materials["aperture"])
    _link_to_collection(aperture, collection)
    return card, aperture

def create_achromat(
    *,
    collection,
    materials: dict[str, object],
    x_mm: float,
    diameter_mm: float,
    thickness_mm: float,
):
    bpy = get_bpy()
    bpy.ops.mesh.primitive_cylinder_add(
        vertices=96,
        radius=diameter_mm / 2.0,
        depth=thickness_mm,
        location=(x_mm, 0.0, 15.0),
        rotation=(0.0, math.radians(90.0), 0.0),
    )
    lens = bpy.context.object
    lens.name = "AC254-100-A-ML Teaching Achromat"
    lens.data.materials.append(materials["glass"])
    _link_to_collection(lens, collection)
    return lens

def create_lens_mount(*, collection, materials: dict[str, object], x_mm: float, diameter_mm: float):
    bpy = get_bpy()
    bpy.ops.mesh.primitive_torus_add(
        major_radius=(diameter_mm / 2.0) + 2.0,
        minor_radius=1.4,
        major_segments=96,
        minor_segments=12,
        location=(x_mm, 0.0, 15.0),
        rotation=(0.0, math.radians(90.0), 0.0),
    )
    mount = bpy.context.object
    mount.name = "Simplified Lens Mount"
    mount.data.materials.append(materials["metal"])
    _link_to_collection(mount, collection)
    return mount
```

- [ ] **Step 4: Implement camera helpers**

Create `simulations/blender/altair_blender/cameras.py` with:

```python
"""Camera helpers for Blender optics alignment scenes."""

from __future__ import annotations

import math

from .scene import get_bpy

def create_wide_camera():
    bpy = get_bpy()
    bpy.ops.object.camera_add(
        location=(35.0, -95.0, 55.0),
        rotation=(math.radians(62.0), 0.0, math.radians(31.0)),
    )
    camera = bpy.context.object
    camera.name = "Wide Setup Camera"
    camera.data.lens = 35
    camera.data.dof.use_dof = True
    camera.data.dof.focus_distance = 95.0
    bpy.context.scene.camera = camera
    return camera

def create_card_closeup_camera(*, card_x_mm: float):
    bpy = get_bpy()
    bpy.ops.object.camera_add(
        location=(card_x_mm - 24.0, -28.0, 20.0),
        rotation=(math.radians(78.0), 0.0, math.radians(-38.0)),
    )
    camera = bpy.context.object
    camera.name = "Card Close-Up Camera"
    camera.data.lens = 80
    camera.data.dof.use_dof = True
    camera.data.dof.focus_distance = 30.0
    return camera
```

- [ ] **Step 5: Run import-contract tests**

Run:

```bash
uv run pytest tests/test_blender_import_contracts.py -q
```

Expected: `2 passed`.

- [ ] **Step 6: Run lint**

Run:

```bash
uv run ruff check simulations/blender/altair_blender/geometry.py simulations/blender/altair_blender/cameras.py tests/test_blender_import_contracts.py
```

Expected: `All checks passed!`

- [ ] **Step 7: Commit geometry and cameras**

Run:

```bash
git add simulations/blender/altair_blender/geometry.py simulations/blender/altair_blender/cameras.py tests/test_blender_import_contracts.py
git commit -m "feat: add blender geometry and camera helpers"
```

Expected: commit succeeds.

## Task 5: Add Animation And Beam Visualization Helpers

**Files:**
- Create: `simulations/blender/altair_blender/animation.py`
- Modify: `simulations/blender/altair_blender/optics.py`
- Modify: `tests/test_blender_import_contracts.py`

- [ ] **Step 1: Extend import-contract tests for animation and beam helpers**

Modify `tests/test_blender_import_contracts.py` to:

```python
import importlib

import pytest

def test_core_modules_import_without_blender():
    scene = importlib.import_module("simulations.blender.altair_blender.scene")
    materials = importlib.import_module("simulations.blender.altair_blender.materials")
    geometry = importlib.import_module("simulations.blender.altair_blender.geometry")
    cameras = importlib.import_module("simulations.blender.altair_blender.cameras")
    animation = importlib.import_module("simulations.blender.altair_blender.animation")
    optics = importlib.import_module("simulations.blender.altair_blender.optics")

    assert callable(scene.get_bpy)
    assert callable(scene.reset_scene)
    assert callable(scene.configure_scene)
    assert callable(scene.ensure_collection)
    assert callable(materials.create_materials)
    assert callable(geometry.create_optical_table)
    assert callable(geometry.create_business_card)
    assert callable(geometry.create_achromat)
    assert callable(geometry.create_lens_mount)
    assert callable(cameras.create_wide_camera)
    assert callable(cameras.create_card_closeup_camera)
    assert callable(animation.keyframe_transform)
    assert callable(animation.set_linear_interpolation)
    assert callable(optics.create_beam_between)
    assert callable(optics.create_return_spot)

def test_get_bpy_reports_clear_error_outside_blender():
    scene = importlib.import_module("simulations.blender.altair_blender.scene")

    with pytest.raises(RuntimeError, match="Blender"):
        scene.get_bpy()
```

- [ ] **Step 2: Run tests and verify they fail**

Run:

```bash
uv run pytest tests/test_blender_import_contracts.py -q
```

Expected: FAIL because `animation.py` does not exist and `optics.create_beam_between` is missing.

- [ ] **Step 3: Implement animation helpers**

Create `simulations/blender/altair_blender/animation.py` with:

```python
"""Animation helpers for Blender optics simulations."""

from __future__ import annotations

def keyframe_transform(obj, *, frame: int, location=None, rotation_euler=None) -> None:
    """Set optional transforms and insert keyframes for them."""

    if location is not None:
        obj.location = location
        obj.keyframe_insert(data_path="location", frame=frame)
    if rotation_euler is not None:
        obj.rotation_euler = rotation_euler
        obj.keyframe_insert(data_path="rotation_euler", frame=frame)

def keyframe_visibility(obj, *, frame: int, visible: bool) -> None:
    """Keyframe viewport and render visibility together."""

    obj.hide_viewport = not visible
    obj.hide_render = not visible
    obj.keyframe_insert(data_path="hide_viewport", frame=frame)
    obj.keyframe_insert(data_path="hide_render", frame=frame)

def set_linear_interpolation(obj) -> None:
    """Set all animation curves for an object to linear interpolation."""

    if obj.animation_data is None or obj.animation_data.action is None:
        return
    for fcurve in obj.animation_data.action.fcurves:
        for keyframe in fcurve.keyframe_points:
            keyframe.interpolation = "LINEAR"
```

- [ ] **Step 4: Add Blender beam and return-spot helpers to optics.py**

Append this code to `simulations/blender/altair_blender/optics.py`:

```python

def create_beam_between(
    *,
    name: str,
    start_xyz: tuple[float, float, float],
    end_xyz: tuple[float, float, float],
    radius_mm: float,
    material,
    collection,
):
    """Create a glowing cylindrical beam between two scene points."""

    from mathutils import Vector  # type: ignore[import-not-found]

    from .scene import get_bpy

    validate_positive("radius_mm", radius_mm)
    bpy = get_bpy()
    start = Vector(start_xyz)
    end = Vector(end_xyz)
    direction = end - start
    length = direction.length
    validate_positive("beam_length", length)

    midpoint = start + (direction * 0.5)
    bpy.ops.mesh.primitive_cylinder_add(vertices=32, radius=radius_mm, depth=length, location=midpoint)
    beam = bpy.context.object
    beam.name = name
    beam.rotation_euler = direction.to_track_quat("Z", "Y").to_euler()
    beam.data.materials.append(material)
    for existing in beam.users_collection:
        existing.objects.unlink(beam)
    collection.objects.link(beam)
    return beam

def create_return_spot(
    *,
    name: str,
    card_x_mm: float,
    offset: SpotOffset,
    radius_mm: float,
    material,
    collection,
):
    """Create a small return spot on the card face."""

    from .scene import get_bpy

    validate_positive("radius_mm", radius_mm)
    bpy = get_bpy()
    bpy.ops.mesh.primitive_uv_sphere_add(
        segments=32,
        ring_count=16,
        radius=radius_mm,
        location=(card_x_mm - 0.9, offset.y_mm, 15.0 + offset.z_mm),
    )
    spot = bpy.context.object
    spot.name = name
    spot.scale.x = 0.18
    spot.data.materials.append(material)
    for existing in spot.users_collection:
        existing.objects.unlink(spot)
    collection.objects.link(spot)
    return spot
```

- [ ] **Step 5: Run tests**

Run:

```bash
uv run pytest tests/test_blender_optics_math.py tests/test_blender_import_contracts.py -q
```

Expected: all tests pass.

- [ ] **Step 6: Run lint**

Run:

```bash
uv run ruff check simulations/blender/altair_blender tests/test_blender_optics_math.py tests/test_blender_import_contracts.py
```

Expected: `All checks passed!`

- [ ] **Step 7: Commit animation and beam helpers**

Run:

```bash
git add simulations/blender/altair_blender/animation.py simulations/blender/altair_blender/optics.py tests/test_blender_import_contracts.py
git commit -m "feat: add blender beam and animation helpers"
```

Expected: commit succeeds.

## Task 6: Add The Achromat Back-Reflection Scene Script

**Files:**
- Create: `simulations/blender/scenes/achromat_back_reflection.py`
- Create: `tests/test_achromat_scene_contract.py`

- [ ] **Step 1: Write failing scene contract tests**

Create `tests/test_achromat_scene_contract.py` with:

```python
import importlib.util
from pathlib import Path

SCENE_PATH = Path("simulations/blender/scenes/achromat_back_reflection.py")

def load_scene_module():
    spec = importlib.util.spec_from_file_location("achromat_back_reflection", SCENE_PATH)
    module = importlib.util.module_from_spec(spec)
    assert spec is not None
    assert spec.loader is not None
    spec.loader.exec_module(module)
    return module

def test_scene_script_imports_without_running_blender():
    module = load_scene_module()

    assert module.SCENE_NAME == "achromat_back_reflection"
    assert callable(module.main)

def test_scene_default_parameters_match_first_demo():
    module = load_scene_module()
    params = module.DEFAULT_PARAMETERS

    assert params["wavelength_nm"] == 561.0
    assert params["beam_diameter_mm"] == 1.0
    assert params["aperture_diameter_mm"] == 1.0
    assert params["lens_focal_length_mm"] == 100.0
    assert params["lens_diameter_mm"] == 25.4
    assert params["initial_tilt_y_deg"] != 0.0
    assert params["initial_decenter_y_mm"] != 0.0
    assert params["exaggeration"] > 1.0
```

- [ ] **Step 2: Run scene contract tests and verify they fail**

Run:

```bash
uv run pytest tests/test_achromat_scene_contract.py -q
```

Expected: FAIL because `achromat_back_reflection.py` does not exist.

- [ ] **Step 3: Implement scene script**

Create `simulations/blender/scenes/achromat_back_reflection.py` with:

```python
"""Generate the achromat back-reflection alignment teaching scene."""

from __future__ import annotations

import math
from pathlib import Path
import sys

SCENE_NAME = "achromat_back_reflection"

DEFAULT_PARAMETERS = {
    "wavelength_nm": 561.0,
    "beam_diameter_mm": 1.0,
    "aperture_diameter_mm": 1.0,
    "lens_focal_length_mm": 100.0,
    "lens_diameter_mm": 25.4,
    "lens_thickness_mm": 9.0,
    "card_x_mm": 0.0,
    "lens_x_mm": 75.0,
    "initial_tilt_y_deg": 0.28,
    "initial_tilt_z_deg": -0.16,
    "initial_decenter_y_mm": 0.28,
    "initial_decenter_z_mm": -0.18,
    "exaggeration": 8.0,
    "frame_start": 1,
    "frame_tilt_corrected": 72,
    "frame_decenter_corrected": 132,
    "frame_end": 168,
}

def _ensure_repo_root_on_path() -> None:
    repo_root = Path(__file__).resolve().parents[3]
    if str(repo_root) not in sys.path:
        sys.path.insert(0, str(repo_root))

def _parse_output_path(argv: list[str]) -> str | None:
    if "--" not in argv:
        return None
    separator = argv.index("--")
    extra = argv[separator + 1 :]
    if not extra:
        return None
    return extra[0]

def main(output_path: str | None = None) -> None:
    _ensure_repo_root_on_path()

    from simulations.blender.altair_blender.animation import keyframe_transform, set_linear_interpolation
    from simulations.blender.altair_blender.cameras import create_card_closeup_camera, create_wide_camera
    from simulations.blender.altair_blender.geometry import (
        create_achromat,
        create_business_card,
        create_lens_mount,
        create_optical_table,
    )
    from simulations.blender.altair_blender.materials import create_materials
    from simulations.blender.altair_blender.optics import (
        compute_return_spots,
        create_beam_between,
        create_return_spot,
        validate_positive,
    )
    from simulations.blender.altair_blender.scene import (
        configure_scene,
        ensure_collection,
        get_bpy,
        reset_scene,
        validate_output_path,
    )

    params = DEFAULT_PARAMETERS
    validate_positive("beam_diameter_mm", params["beam_diameter_mm"])
    validate_positive("aperture_diameter_mm", params["aperture_diameter_mm"])
    validate_positive("lens_diameter_mm", params["lens_diameter_mm"])

    bpy = get_bpy()
    reset_scene()
    configure_scene(
        frame_start=int(params["frame_start"]),
        frame_end=int(params["frame_end"]),
        fps=24,
    )

    collection = ensure_collection("Achromat Back Reflection")
    materials = create_materials()

    card_x = params["card_x_mm"]
    lens_x = params["lens_x_mm"]
    beam_radius = params["beam_diameter_mm"] / 2.0

    create_optical_table(collection=collection, materials=materials)
    create_business_card(
        collection=collection,
        materials=materials,
        x_mm=card_x,
        width_mm=88.0,
        height_mm=50.0,
        aperture_diameter_mm=params["aperture_diameter_mm"],
    )
    lens = create_achromat(
        collection=collection,
        materials=materials,
        x_mm=lens_x,
        diameter_mm=params["lens_diameter_mm"],
        thickness_mm=params["lens_thickness_mm"],
    )
    mount = create_lens_mount(
        collection=collection,
        materials=materials,
        x_mm=lens_x,
        diameter_mm=params["lens_diameter_mm"],
    )

    create_beam_between(
        name="Incident 561 nm Beam",
        start_xyz=(-42.0, 0.0, 15.0),
        end_xyz=(lens_x + 18.0, 0.0, 15.0),
        radius_mm=beam_radius,
        material=materials["laser"],
        collection=collection,
    )

    initial_spots = compute_return_spots(
        tilt_y_deg=params["initial_tilt_y_deg"],
        tilt_z_deg=params["initial_tilt_z_deg"],
        decenter_y_mm=params["initial_decenter_y_mm"],
        decenter_z_mm=params["initial_decenter_z_mm"],
        card_to_lens_mm=lens_x - card_x,
        exaggeration=params["exaggeration"],
    )
    centered_spots = compute_return_spots(
        tilt_y_deg=0.0,
        tilt_z_deg=0.0,
        decenter_y_mm=0.0,
        decenter_z_mm=0.0,
        card_to_lens_mm=lens_x - card_x,
        exaggeration=params["exaggeration"],
    )

    spot_a = create_return_spot(
        name="Return Spot A",
        card_x_mm=card_x,
        offset=initial_spots[0],
        radius_mm=0.65,
        material=materials["spot_a"],
        collection=collection,
    )
    spot_b = create_return_spot(
        name="Return Spot B",
        card_x_mm=card_x,
        offset=initial_spots[1],
        radius_mm=0.55,
        material=materials["spot_b"],
        collection=collection,
    )

    for obj in (lens, mount):
        keyframe_transform(
            obj,
            frame=int(params["frame_start"]),
            rotation_euler=(0.0, math.radians(90.0 + params["initial_tilt_z_deg"]), math.radians(params["initial_tilt_y_deg"])),
            location=(lens_x, params["initial_decenter_y_mm"], 15.0 + params["initial_decenter_z_mm"]),
        )
        keyframe_transform(
            obj,
            frame=int(params["frame_tilt_corrected"]),
            rotation_euler=(0.0, math.radians(90.0), 0.0),
            location=(lens_x, params["initial_decenter_y_mm"], 15.0 + params["initial_decenter_z_mm"]),
        )
        keyframe_transform(
            obj,
            frame=int(params["frame_decenter_corrected"]),
            rotation_euler=(0.0, math.radians(90.0), 0.0),
            location=(lens_x, 0.0, 15.0),
        )
        set_linear_interpolation(obj)

    for spot, final_offset in zip((spot_a, spot_b), centered_spots):
        spot.keyframe_insert(data_path="location", frame=int(params["frame_start"]))
        spot.location = (card_x - 0.9, final_offset.y_mm, 15.0 + final_offset.z_mm)
        spot.keyframe_insert(data_path="location", frame=int(params["frame_decenter_corrected"]))
        set_linear_interpolation(spot)

    create_wide_camera()
    create_card_closeup_camera(card_x_mm=card_x)

    output = validate_output_path(output_path)
    if output is not None:
        bpy.ops.wm.save_as_mainfile(filepath=str(output))

if __name__ == "__main__":
    main(_parse_output_path(sys.argv))
```

- [ ] **Step 4: Run scene contract tests**

Run:

```bash
uv run pytest tests/test_achromat_scene_contract.py -q
```

Expected: `2 passed`.

- [ ] **Step 5: Run all non-Blender tests for the simulation area**

Run:

```bash
uv run pytest tests/test_blender_optics_math.py tests/test_blender_import_contracts.py tests/test_achromat_scene_contract.py -q
```

Expected: all tests pass.

- [ ] **Step 6: Run lint on the simulation area**

Run:

```bash
uv run ruff check simulations/blender tests/test_blender_optics_math.py tests/test_blender_import_contracts.py tests/test_achromat_scene_contract.py
```

Expected: `All checks passed!`

- [ ] **Step 7: Commit scene script**

Run:

```bash
git add simulations/blender/scenes/achromat_back_reflection.py tests/test_achromat_scene_contract.py
git commit -m "feat: add achromat back-reflection blender scene"
```

Expected: commit succeeds.

## Task 7: Verify Blender Smoke Path And Final Documentation

**Files:**
- Modify: `simulations/blender/README.md`
- Modify: `simulations/blender/AGENTS.md` only if verification reveals a durable run note.

- [ ] **Step 1: Check whether Blender is available**

Run:

```bash
command -v blender
```

Expected if Blender is installed: prints the Blender executable path.

Expected if Blender is not installed: exits nonzero with no output. In that case, skip Step 2 and document in the final handoff that Blender smoke verification could not be run locally.

- [ ] **Step 2: Run the scene in Blender when available**

Run:

```bash
blender --background --python simulations/blender/scenes/achromat_back_reflection.py
```

Expected: Blender exits with status 0 and does not report Python exceptions.

- [ ] **Step 3: Save a temporary `.blend` file outside source control when Blender is available**

Run:

```bash
mkdir -p /tmp/altair-blender-smoke
blender --background --python simulations/blender/scenes/achromat_back_reflection.py -- /tmp/altair-blender-smoke/achromat_back_reflection.blend
test -f /tmp/altair-blender-smoke/achromat_back_reflection.blend
```

Expected: all commands exit with status 0. Do not commit the generated file.

- [ ] **Step 4: Update README with verification note if needed**

If Blender was unavailable, append this section to `simulations/blender/README.md`:

````markdown
## Local Verification Notes

The non-Blender tests exercise import safety, parameter validation, and the
teaching-level return-spot math. Full scene generation requires Blender on
`PATH` and should be smoke-tested with:

```bash
blender --background --python simulations/blender/scenes/achromat_back_reflection.py
```
````

If Blender was available and the smoke test passed, no README change is required.

- [ ] **Step 5: Run final non-Blender verification**

Run:

```bash
uv run pytest tests/test_blender_optics_math.py tests/test_blender_import_contracts.py tests/test_achromat_scene_contract.py -q
uv run ruff check simulations/blender tests/test_blender_optics_math.py tests/test_blender_import_contracts.py tests/test_achromat_scene_contract.py
git diff --check
```

Expected: pytest passes, ruff reports `All checks passed!`, and `git diff --check` has no output.

- [ ] **Step 6: Inspect source-control status**

Run:

```bash
git status --short
```

Expected:

- If Blender was unavailable and README was updated, only `simulations/blender/README.md` is modified.
- If Blender was available and no docs update was required, no output.

- [ ] **Step 7: Commit final verification docs only if README or AGENTS changed**

Run this only when Step 6 shows documentation changes:

```bash
git add simulations/blender/README.md simulations/blender/AGENTS.md
git commit -m "docs: update blender simulation verification notes"
```

Expected: commit succeeds when there are documentation changes. If there are no changes, do not create an empty commit.

## Final Handoff Checklist

Before reporting completion:

- [ ] Run `git log --oneline -5` and include the new commits in the handoff.
- [ ] Run `git status --short` and confirm whether the tree is clean.
- [ ] Report exact verification commands run and whether Blender smoke verification was run or skipped.
- [ ] Do not claim rendered video or generated `.blend` artifacts were committed.
- [ ] Mention that the first script is the source of truth for the scene.

## Plan Self-Review

Spec coverage:

- Dedicated `simulations/blender/` area: Task 1.
- Reusable helper modules: Tasks 2 through 5.
- Local `AGENTS.md`: Task 1.
- First achromat back-reflection scene: Task 6.
- Hybrid educational model and explicit approximation boundary: Tasks 1, 2, 6.
- Parameterized values for 561 nm beam, 1 mm beam/aperture, 100 mm focal length, lens diameter, tilt, decenter, and exaggeration: Task 6.
- Wide and close-up cameras: Tasks 4 and 6.
- Tests without Blender plus optional Blender smoke: Tasks 2, 3, 4, 5, 6, and 7.
- Documentation and generated-artifact policy: Tasks 1 and 7.

Placeholder scan: no unfinished-work markers or unspecified edge-handling steps remain.

Type consistency: `SpotOffset`, `compute_return_spots`, `validate_positive`, `get_bpy`, `create_materials`, geometry helpers, camera helpers, animation helpers, and scene constants are defined before later tasks rely on them.

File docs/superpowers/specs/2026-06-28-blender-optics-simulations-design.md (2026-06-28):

# Blender Optics Simulations Design

Date: 2026-06-28

## Purpose

Create a reusable Blender Python simulation area in the Altair repository for
educational optics-alignment videos. The first simulation will demonstrate how
to align an achromatic doublet by observing two back-reflection spots on a
business card target with a small aperture.

The first deliverable is a Blender Python scene generator, not a committed
`.blend` file or rendered movie. The script should generate the scene when run
inside Blender and should be structured so future simulations can reuse the
same helper modules.

## Scope

In scope:

- Add a dedicated simulation area under `simulations/blender/`.
- Build a small reusable Python helper package for Blender scene construction.
- Add a local `AGENTS.md` file with subproject context for future agents.
- Add one scene generator for the achromatic-doublet back-reflection demo.
- Use Blender's Python API as the scene-generation interface.
- Use a hybrid teaching model: physically plausible geometry with visual
  exaggeration where needed for clarity.

Out of scope for the first implementation:

- Exact wave-optics simulation.
- Exact Fresnel/refraction modeling.
- Importing Zemax files or manufacturer prescription data.
- Committing rendered movies or generated `.blend` files.
- Building an external command-line application around Blender.

## Repository Layout

The implementation should add:

```text
simulations/
  blender/
    AGENTS.md
    README.md
    altair_blender/
      __init__.py
      animation.py
      cameras.py
      geometry.py
      materials.py
      optics.py
      scene.py
    scenes/
      achromat_back_reflection.py
```

`simulations/blender/AGENTS.md` should be maintained as the local context file
for this subproject. It should record coordinate conventions, scale choices,
run commands, modeling approximations, naming conventions, and durable decisions
that future simulations should preserve.

## First Scene

The first scene will be `simulations/blender/scenes/achromat_back_reflection.py`.
It will generate a clean hybrid view of an optical alignment workflow:

- Simplified optical table and mount references.
- Business card target with a centered aperture of about 1 mm.
- Narrow 561 nm collimated laser beam with about 1 mm diameter.
- Mounted 1 inch achromatic doublet modeled after Thorlabs AC254-100-A-ML
  parameters at the teaching level: 100 mm focal length, visible AR coating,
  and 1 inch mounted optic scale.
- Two visible back-reflection paths from the lens surfaces.
- Two return spots on the business card face.
- Wide camera showing the setup.
- Card close-up camera showing the aperture and return spots.

The scene should be parameterized near the top of the scene script. Parameters
should include beam diameter, wavelength, aperture diameter, lens focal length,
lens diameter, initial tilt, initial decenter, timeline length, and visual
exaggeration.

## Animation Behavior

The default timeline should show a complete alignment story:

1. Opening state: the lens is misaligned; two return spots are displaced from
   the aperture.
2. Tilt correction: the lens angle is adjusted; the return spots move toward
   the aperture.
3. Decenter correction: the lens lateral position is adjusted; the spots become
   more symmetric and centered.
4. Final aligned state: both return spots are centered on the aperture, with a
   brief hold for the viewer.

The back-reflection spot motion should be visually legible. Small physical
tilts and decenters may be scaled for teaching using an explicit exaggeration
parameter. The code and documentation should make clear that this is an
educational geometric model, not a quantitative optical design solver.

## Reusable Modules

`scene.py`:

- Reset the Blender scene.
- Configure units, frame range, render resolution, and basic world lighting.
- Provide safe object-collection helpers.

`materials.py`:

- Create reusable materials for glass, 561 nm laser glow, return spots, matte
  card stock, metal mounts, table surface, and subtle labels.

`geometry.py`:

- Build optical table features, card target, aperture ring, lens barrel,
  simplified achromatic doublet mesh, and basic mount geometry.

`optics.py`:

- Build incident beam and reflected beam visualizations.
- Compute teaching-level return-spot positions from tilt and decenter
  parameters.
- Keep all physical simplifications localized and documented.

`animation.py`:

- Add keyframes for object transforms and material intensity/visibility.
- Provide interpolation helpers for alignment phases.

`cameras.py`:

- Create and name the wide camera.
- Create and name the card close-up camera.
- Configure focal lengths, clipping, depth of field, and timeline markers for
  camera switching if used later.

## Data Flow

The scene script defines the simulation parameters and timeline phases. It then
calls reusable helpers in this order:

1. Reset scene and configure render settings.
2. Create materials.
3. Build static geometry: table, card, aperture, mount, lens.
4. Build beam geometry and return-spot markers from the initial parameter set.
5. Add keyframes for lens tilt, lens decenter, reflected beams, and card spots.
6. Add wide and close-up cameras.
7. Save the generated scene only when an explicit output path is provided.

The generated Blender scene is the output. The Python source remains the source
of truth.

## Error Handling

The first implementation should fail early with clear messages when:

- It is not run from Blender and `bpy` is unavailable.
- Required Blender APIs are missing.
- A numeric scene parameter is nonsensical, such as a nonpositive aperture
  diameter or beam diameter.
- An optional save path points to a directory that does not exist.

Errors should be plain Python exceptions with actionable messages. The helper
modules should avoid silently swallowing Blender API failures.

## Testing And Verification

Because Blender may not be installed in every development environment, tests
should be split into two levels:

- Standard Python checks that can run without Blender for parameter validation,
  alignment math, and import-safe modules that do not require `bpy` at import
  time.
- Manual or optional Blender verification that runs the scene script inside
  Blender and confirms that the scene generates without errors.

Recommended verification for the first implementation:

```bash
uv run pytest
uv run ruff check simulations/blender
blender --background --python simulations/blender/scenes/achromat_back_reflection.py
```

If Blender is unavailable, document that limitation and still run the Python
checks that do not require Blender.

## Documentation

`simulations/blender/README.md` should explain:

- What the simulation directory contains.
- How to run the first scene in Blender.
- Which files are source-controlled outputs and which are generated artifacts.
- The intentional approximation boundary between teaching visualization and
  physical optical simulation.

The main Sphinx docs do not need to link the simulation in the first
implementation unless the generated script is stable and easy to run.

## References

- Blender Python API quickstart:
  https://docs.blender.org/api/current/info_quickstart.html
- Thorlabs AC254-100-A-ML product page:
  https://www.thorlabs.com/item/AC254-100-A-ML

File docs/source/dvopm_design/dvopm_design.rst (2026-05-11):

.. _dvopmdesign-home:

##############################
Design Process
##############################

Detection Path: Design
______________________

The detection path is designed as a compact remote-imaging relay that projects the oblique image plane directly onto the camera sensor.

The relay is formed using a pair of photographic lenses: a 65 mm Mitakon Zhongyi Speedmaster lens (O1) and an 85 mm Nikon AF-S NIKKOR lens (O2). The use of photographic lenses enables a compact and mechanically accessible relay configuration while allowing intermediate components to be incorporated within the optical path. The focal length ratio of these lenses provides an effective magnification of approximately 1.308×, which sets the image scale at the sensor.

An emission filter wheel is positioned between the two lenses to enable fluorescence filtering while preserving the relay geometry. The physical presence of this filter wheel introduces a minimum spacing constraint in the relay, which is carried forward into both the optical and mechanical design.

Image acquisition is performed using a Ximea MU196MR-ON camera with a pixel size of 1.4 µm and an active sensor area of 7.2 mm × 5.4 mm. These parameters define both the sampling and the maximum field of view of the system. With a magnification of 1.308×, the corresponding object-space field of view is approximately:

.. math::

   \frac{7.2\ \text{mm}}{1.308} \approx 5.5\ \text{mm}

This object-space field of view defines the usable imaging region and directly determines the minimum required light-sheet length in the illumination subsystem.

------------------------------

Detection Path: Zemax Simulation Setup
______________________________________

The detection relay was modeled in Zemax using a sequential optical system to evaluate image formation across the field and refine the relay geometry prior to implementation.

The photographic lenses were incorporated using reverse-engineered black-box lens files representing their optical behavior. These models ensure that the Zemax simulation reflects the actual imaging performance of the relay lenses. Additional detail on the construction or validation of these lens files can be provided or referenced elsewhere if required.

The emission filter wheel was modeled as a planar optical element to preserve the physical spacing constraints it introduces within the relay.

The system aperture was defined using the Object Space NA aperture type in Zemax. The value was entered as:

.. math::

   NA = \frac{1}{2 (1.4 + 1.4)} = \frac{1}{5.6} \approx 0.1786

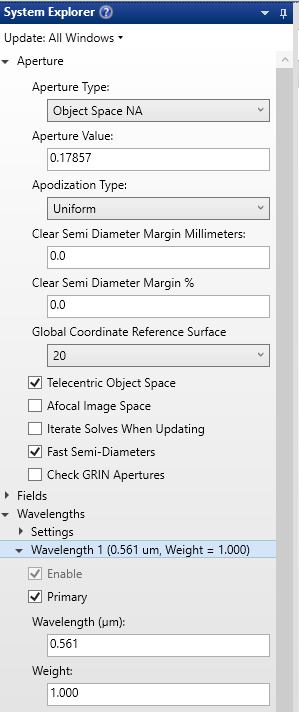
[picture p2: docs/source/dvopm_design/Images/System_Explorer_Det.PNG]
A screenshot of System Explorer in Zemax.


   **Figure 1:** A screenshot of Aperture settings in System Explorer in Zemax

**Object Geometry**

The object surface represents the oblique imaging plane within the specimen. To reproduce the system geometry, it was defined as a plane tilted by 45° and embedded in water.

Because of this tilt, positions across the object correspond to both lateral displacement and changes in depth within the sample. This ensures that the Zemax model accurately reflects the intended imaging condition.

**Field Definition**

A rectangular grid of field points was used to sample the tilted object surface. The field ranges in Zemax were defined as:

- y: −2.75 mm to +2.75 mm (X or X' in physical scheme)
- x: −1 mm to +1 mm  (Y in physical scheme)

The y-range is determined by the camera-limited field of view (~5.5 mm object space). The x-range is constrained by the specimen thickness intersected by the tilted plane. Because of the 45° tilt, displacement along x corresponds to a change in depth within the specimen. For a specimen thickness of approximately 2 mm, the field was restricted to ±1 mm so that all field points remain within the sample.

The fields themselves were weighted to prioritize central regions. The x and y coordinates in the Optimization Wizard were not independently weighted; rather, the weighting was applied through the field definitions, which influences the optimization process.

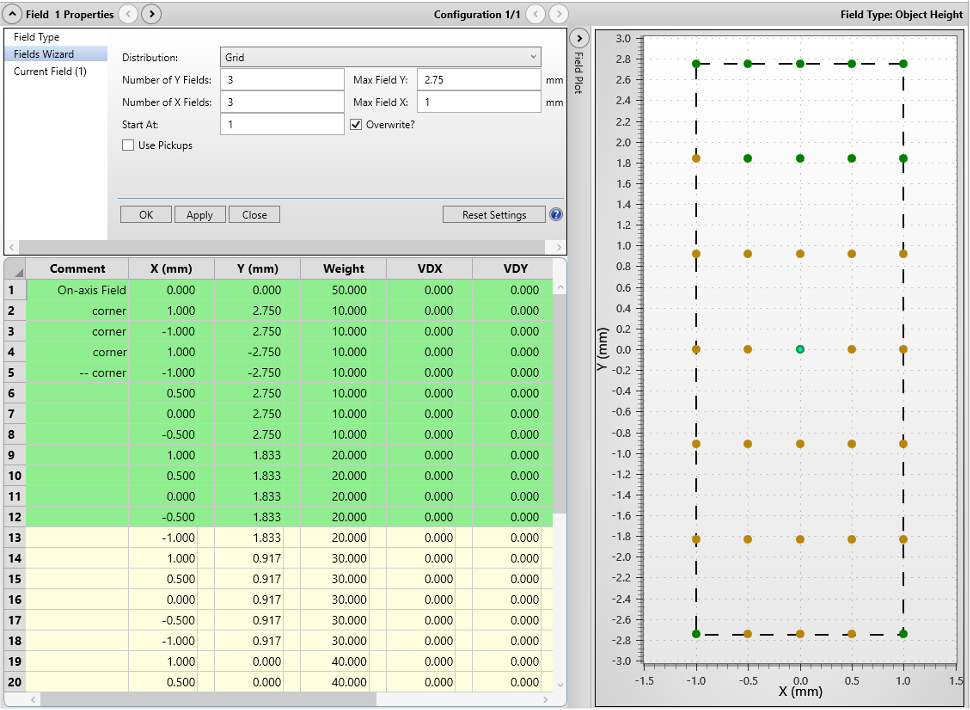
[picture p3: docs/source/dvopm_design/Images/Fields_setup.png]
Screenshot of fields setup settigns


   **Figure 2:** Settings and Plot of field points in Zemax on a 2D plane

Because the object is tilted, this setup is essentially a 3D visualization, where the field points on the xy plane are also having different depth or z.

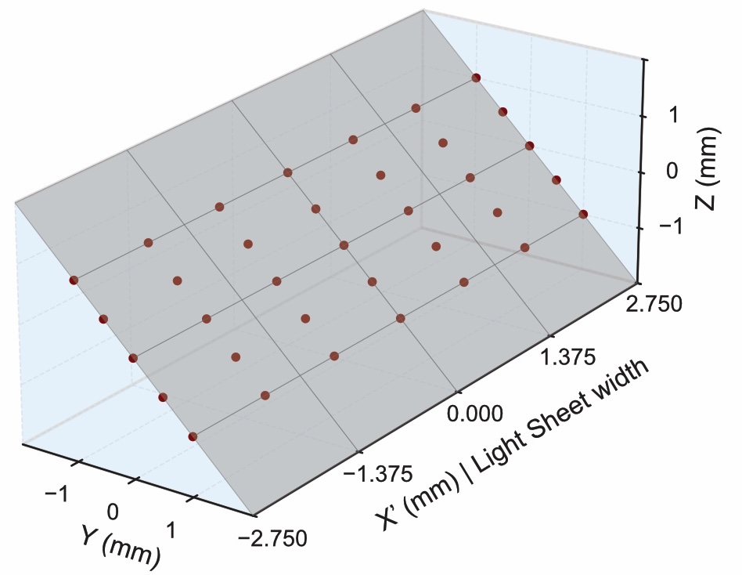
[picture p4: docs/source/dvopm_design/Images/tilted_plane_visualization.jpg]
Schematic of a Fields setup in a physical sense


   **Figure 3:** A 3D visualization of the object surface and field points in the object as modelled in Zemax

**Optimization**

The detection relay was refined using the Zemax Optimization Wizard.

The primary optimization variables were:
- relay distances  
- camera (image plane) tilt  

The relay distances correspond to the physical separations between system components:
- specimen to O1  
- O1 to fold mirror (minimum spacing set by filter wheel)  
- fold mirror to O2 (minimum spacing set by kinematic mount)  
- O2 to camera  

Among these, the O2-to-camera distance and the camera tilt angle were found to be the most sensitive parameters. These directly control image plane alignment and defocus sensitivity, making them the dominant contributors to final image quality.

Because the system images an oblique plane, the image surface was allowed to tilt so that it aligns with the projected image formed by the relay.

The folllowing optimization settings were used:
- Image Quality: Spot  
- Reference: Centroid  
- Gaussian Quadrature: maximum arms and rings 

The optimization process was carried out iteratively, adjusting one parameter at a time to improve focus and reduce aberrations across the field. The resulting configuration established the final geometric arrangement of the detection relay used in the physical implementation of the system.

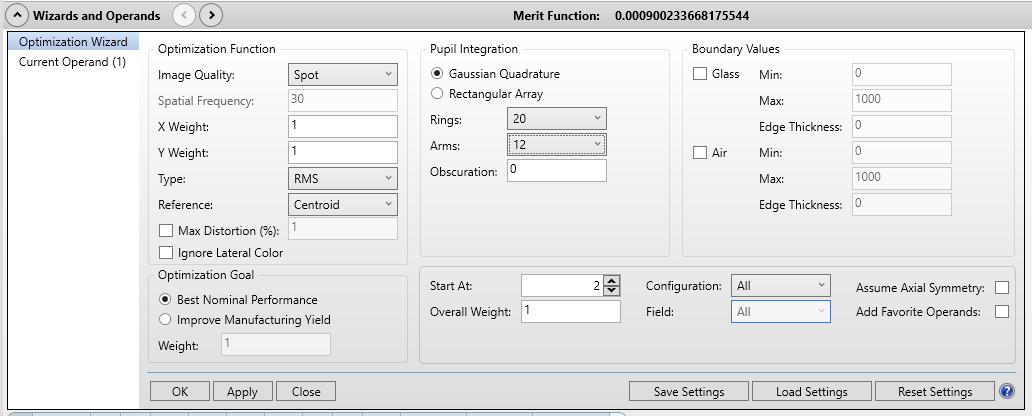
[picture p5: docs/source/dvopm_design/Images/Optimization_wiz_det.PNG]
Screenshot of the Optimization Wizard in Zemax


   **Figure 4:** Optimization Wizard in Zemax. We are optimizng for the spot size of our detection path.

Detection Path: Zemax Analysis
______________________________

The imaging performance of the detection path was evaluated using the modulation transfer function (MTF). The MTF describes how effectively the optical system transfers contrast at different spatial frequencies from the object to the image. Low spatial frequencies correspond to coarse features, while higher spatial frequencies correspond to finer details. As spatial frequency increases, contrast decreases due to aberrations and diffraction, and the MTF curve captures this behavior.

MTF was computed at each field point in both tangential and sagittal directions. These two directions are defined locally at each field point and correspond to orthogonal orientations of spatial variation. In general, the tangential direction lies along the direction of increasing field height, while the sagittal direction is orthogonal to it. Because these directions are defined locally, they rotate across the field and do not correspond directly to global x and y axes.

Resolution was quantified using the MTF20 criterion, defined as the spatial frequency at which the MTF drops to 20% contrast. This threshold provides a practical measure of the smallest resolvable feature size under typical imaging conditions.

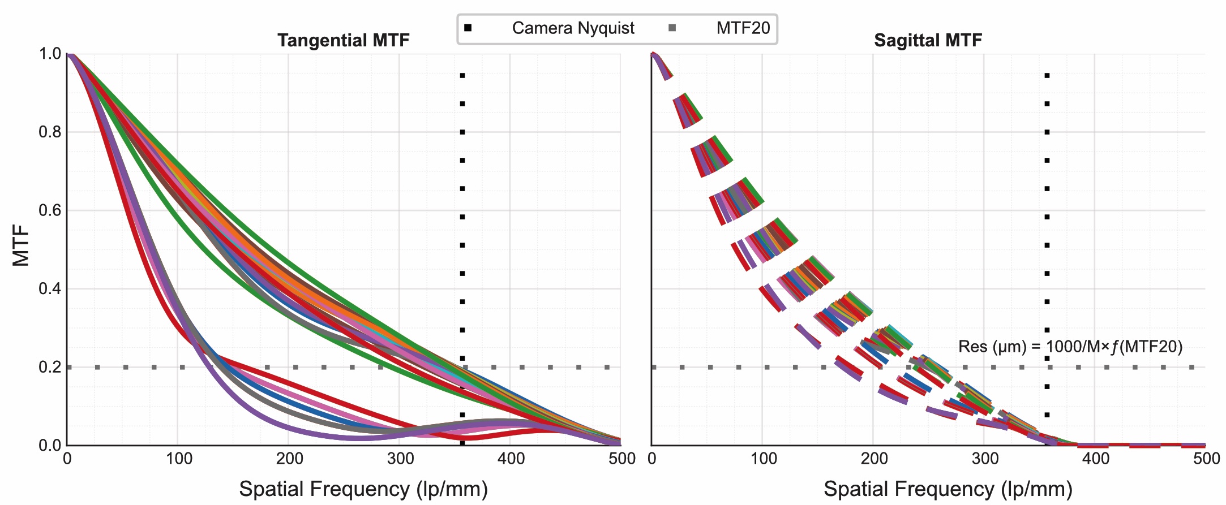
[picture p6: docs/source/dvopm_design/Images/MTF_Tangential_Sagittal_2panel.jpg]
MTF Curves for 35 fields both tangential and sagittal.


   **Figure 5:** MTF curves for all field points in both tangential and sagittal directions

The spatial frequency obtained from Zemax is reported in image space (lp/mm). To express resolution in object space, the following relationship was used:

.. math::

   \mathrm{Resolution} = \frac{1000}{f_{\mathrm{image}} \cdot M}

where :math:`f_{\mathrm{image}}` is the spatial frequency at MTF20 (in lp/mm), :math:`M = 1.308` is the system magnification, and the factor of 1000 converts the result to micrometers.

At the center field, the measured resolutions are:

- Tangential: 2.262885 µm  
- Sagittal: 3.077209 µm  

Across the full field:

- Tangential resolution ranges from approximately 2.18 µm in the central region to 5.94 µm toward the field boundaries  
- Sagittal resolution ranges from approximately 2.95 µm in the central region to 4.43 µm toward the field boundaries  

These results indicate that the best imaging performance is achieved near the central region of the field, where aberrations are minimal. As the field position moves toward the edges, both tangential and sagittal resolutions degrade due to increasing off-axis aberrations. The tangential direction exhibits a larger variation across the field, indicating that it is more sensitive to field-dependent aberrations in this relay configuration.

The full MTF curves provide additional insight beyond the MTF20 metric by showing how contrast decays across spatial frequencies for each field point. In particular, they reveal whether performance degradation occurs gradually or abruptly at different field locations, which is useful for understanding edge-of-field behavior.

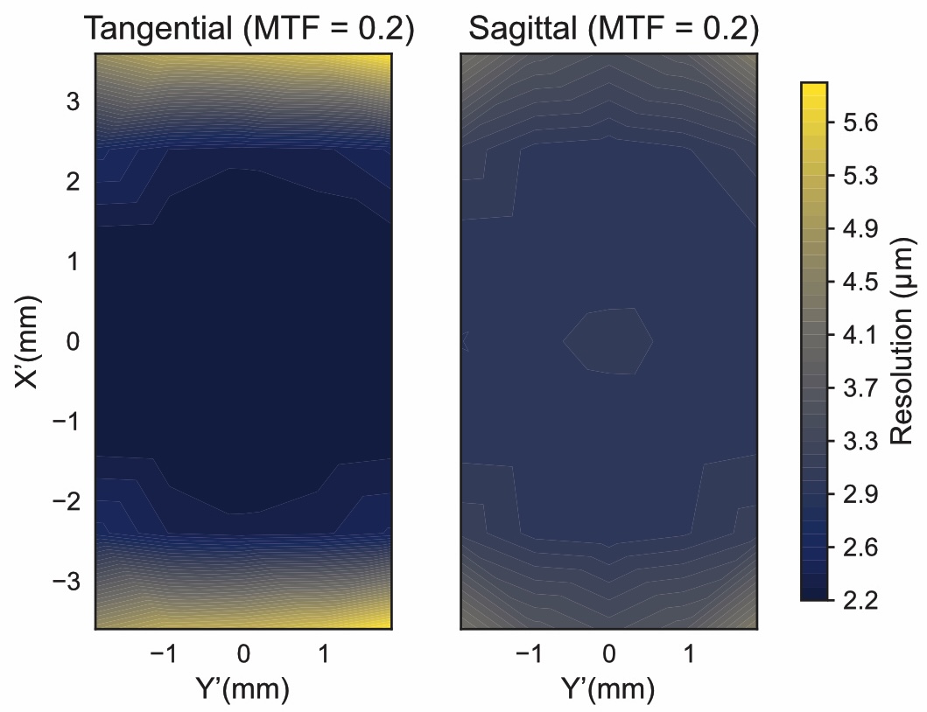
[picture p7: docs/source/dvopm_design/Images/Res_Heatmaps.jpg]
Heatmap visualization of tangential and sagittal resolution


   **Figure 6:** Interpolated heatmaps showing spatial variation of tangential and sagittal resolution across the field

------------------------------

Illumination Path: Design
_________________________

The illumination path was designed to generate an oblique light sheet matched to the detection field of view.
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

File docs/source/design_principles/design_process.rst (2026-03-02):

.. _design-home:

##############
Design Process
##############

Initial Lens Selection
______________________

Prior to starting optical simulations in Zemax, it's convenient to start with straightforward
calculations to determine which lenses to use in the optical train to achieve the desired field of view (FOV) for your
detection path. In our case, our detection path consisted of a 400 mm tube lens and a Nikon 25x/1.1 numerical aperture (NA) immersion detection objective.

Schematic of a standard, widefield detection path.
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

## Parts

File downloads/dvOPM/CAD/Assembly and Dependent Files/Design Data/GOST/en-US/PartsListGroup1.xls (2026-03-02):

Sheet: Лист 1
Инв. № подл |  |  |  | Подп. и дата | Взам. инв. № | Инв. № дубл. |  |  | Подп. и дата
Формат | Зона | Поз. | Обозначение |  |  |  | Наименование |  |  |  |  |  | Кол. на исполнение
 |  |  |  |  |  |  |  |  |  |  |  | Лит.
 |  |  |  |  |  |  |  |  |  |  |  | Код
 |  |  |  |  |  |  |  | Изм. | Лист | № докум | Подпись |  | Дата
 |  |  |  |  |  |  |  | Разраб.
 |  |  |  |  |  |  |  | Пров.
 |  |  |  |  |  |  |  | Н.контр
 |  |  |  |  |  |  |  | Утв.
 |  |  |  |  |  |  |  |  |  |  |  |  |  | Копировал

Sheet: Лист 2
Инв. № подл |  |  |  | Подп. и дата | Взам. инв. № | Инв. № дубл. |  |  | Подп. и дата
Формат | Зона | Поз. | Обозначение |  |  |  | Наименование |  |  |  |  | Кол. на исполнение
 |  |  |  |  |  |  |  | Изм. | Лист | № докум. | Подп. | Дата
 |  |  |  |  |  |  |  |  |  |  |  |  | Копировал
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

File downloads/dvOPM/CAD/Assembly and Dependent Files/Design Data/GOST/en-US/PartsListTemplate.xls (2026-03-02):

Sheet: Лист 1
 | Формат | Зона |  | Поз. |  | Обозначение |  |  |  | Наименование |  |  |  | Кол. | Приме-чание
Подп. и дата
Инв. № дубл.
Взам. инв. №
Подп. и дата
 | Изм. |  | Лист |  | № докум |  | Подпись | Дата
Инв. № подл | Разраб. |  |  |  |  |  |  |  |  |  | Литера |  | Лист |  |  | Листов
 | Пров.
 | Н.контр
 | Утв.
 |  |  |  |  |  |  |  |  | Копировал |  |  | Формат А4

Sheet: Лист 2
 | Формат | Зона |  | Поз. |  | Обозначение |  |  |  | Наименование |  | Кол. | Приме-чание
Подп. и дата
Инв. № дубл.
Взам. инв. №
Подп. и дата
Инв. № подл
 | Изм. |  | Лист |  | № докум. |  | Подп. |  | Дата
 |  |  |  |  |  |  |  | Копировал |  |  | Формат А4
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

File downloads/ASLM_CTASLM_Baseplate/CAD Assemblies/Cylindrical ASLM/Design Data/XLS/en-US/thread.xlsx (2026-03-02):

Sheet: Inch Tapping Threads
I Q X | Inch Tapping Threads |  | Sort Order - 5 |  | External |  |  |  |  |  |  | Internal
 |  |  |  |  |  | Major Dia |  | Pitch Dia |  | Minor Dia |  |  | Minor Dia |  | Pitch Dia |  | Major Dia |  | Tap Drill
Size | Size Suffix | Thread Designation | Custom Thread Designation | TPI | Class | Max | Min | Max | Min | Max | Min | Class | Min | Max | Min | Max | Min | Max | Basic
0.0600 |  | 0-48 | 0-48 | 48 | 2B | 0.0600 | 0.0540 | 0.0480 | 0.0435 | 0.0360 | 0.0330
0.0730 |  | 1-42 | 1-42 | 42 | 2B | 0.0750 | 0.0690 | 0.0620 | 0.0575 | 0.0490 | 0.0460
0.0860 |  | 2-32 | 2-32 | 32 | 2B | 0.0880 | 0.0820 | 0.0760 | 0.0710 | 0.0640 | 0.0600
0.0990 |  | 3-28 | 3-28 | 28 | 2B | 0.1010 | 0.0950 | 0.0880 | 0.0830 | 0.0750 | 0.0710
0.1120 |  | 4-24 | 4-24 | 24 | 2B | 0.1140 | 0.1080 | 0.1000 | 0.0950 | 0.0860 | 0.0820
0.1250 |  | 5-20 | 5-20 | 20 | 2B | 0.1300 | 0.1230 | 0.1120 | 0.1065 | 0.0940 | 0.0900
0.1380 |  | 6-20 | 6-20 | 20 | 2B | 0.1390 | 0.1320 | 0.1215 | 0.1155 | 0.1040 | 0.0990
0.1510 |  | 7-19 | 7-19 | 19 | 2B | 0.1540 | 0.1470 | 0.1345 | 0.1280 | 0.1150 | 0.1090
0.1640 |  | 8-18 | 8-18 | 18 | 2B | 0.1660 | 0.1590 | 0.1440 | 0.1375 | 0.1220 | 0.1160
0.1900 |  | 10-16 | 10-16 | 16 | 2B | 0.1890 | 0.1820 | 0.1650 | 0.1585 | 0.1410 | 0.1350
0.2160 |  | 12-14 | 12-14 | 14 | 2B | 0.2150 | 0.2080 | 0.1895 | 0.1825 | 0.1640 | 0.1570
0.2420 |  | 14-14 | 14-14 | 14 | 2B | 0.2410 | 0.2340 | 0.2130 | 0.2060 | 0.1850 | 0.1780
0.2500 |  | 1/4-14 | 1/4-14 | 14 | 2B | 0.2460 | 0.2370 | 0.2190 | 0.2110 | 0.1920 | 0.1850
0.3125 |  | 5/16-12 | 5/16-12 | 12 | 2B | 0.3150 | 0.3060 | 0.2795 | 0.2710 | 0.2440 | 0.2360
0.3750 |  | 3/8-12 | 3/8-12 | 12 | 2B | 0.3800 | 0.3710 | 0.3445 | 0.3350 | 0.3090 | 0.2990
0.4375 |  | 7/16-10 | 7/16-10 | 10 | 2B | 0.4400 | 0.4290 | 0.3995 | 0.3890 | 0.3590 | 0.3490
0.5000 |  | 1/2-10 | 1/2-10 | 10 | 2B | 0.5040 | 0.4930 | 0.4635 | 0.4530 | 0.4230 | 0.4130

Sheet: Metric Forming Screw Threads
M P X | Metric Forming Screw Threads |  | Sort Order - 6 |  | External |  |  |  |  |  |  | Internal
 |  |  |  |  |  | Major Dia |  | Pitch Dia |  | Minor Dia |  |  | Minor Dia |  | Pitch Dia |  | Major Dia |  | Tap Drill
Size | Size Suffix | Thread Designation | Custom Thread Designation | Pitch | Class | Max | Min | Max | Min | Max | Min | Class | Min | Max | Min | Max | Min | Max | Basic
1.5 |  | 1.5x0.5 | 1.5x0.5 | 0.5 | 6g | 1.520 | 1.380 | 1.215 | 1.110 | 0.910 | 0.840
1.5 |  | ST1.5x0.5 | ST1.5x0.5 | 0.5 | 6g | 1.520 | 1.380 | 1.215 | 1.110 | 0.910 | 0.840
1.9 |  | 1.9x0.6 | 1.9x0.6 | 0.6 | 6g | 1.900 | 1.760 | 1.570 | 1.465 | 1.240 | 1.170
1.9 |  | ST1.9x0.6 | ST1.9x0.6 | 0.6 | 6g | 1.900 | 1.760 | 1.570 | 1.465 | 1.240 | 1.170
2.2 |  | 2.2x0.8 | 2.2x0.8 | 0.8 | 6g | 2.240 | 2.100 | 1.935 | 1.810 | 1.630 | 1.520
2.2 |  | ST2.2x0.8 | ST2.2x0.8 | 0.8 | 6g | 2.240 | 2.100 | 1.935 | 1.810 | 1.630 | 1.520
2.6 |  | 2.6x0.9 | 2.6x0.9 | 0.9 | 6g | 2.570 | 2.430 | 2.235 | 2.115 | 1.900 | 1.800
2.6 |  | ST2.6x0.9 | ST2.6x0.9 | 0.9 | 6g | 2.570 | 2.430 | 2.235 | 2.115 | 1.900 | 1.800
2.9 |  | 2.9x1 | 2.9x1 | 1 | 6g | 2.900 | 2.760 | 2.540 | 2.420 | 2.180 | 2.080
2.9 |  | 2.9x1.1 | 2.9x1.1 | 1.1 | 6g | 2.900 | 2.760 | 2.540 | 2.420 | 2.180 | 2.080
2.9 |  | ST2.9x1.1 | ST2.9x1.1 | 1.1 | 6g | 2.900 | 2.760 | 2.540 | 2.420 | 2.180 | 2.080
2.9 |  | 2.9x1.3 | 2.9x1.3 | 1.3 | 6g | 2.900 | 2.720 | 2.540 | 2.355 | 1.890 | 1.700
2.9 |  | 2.9x1.4 | 2.9x1.4 | 1.4 | 6g | 2.900 | 2.720 | 2.340 | 2.175 | 1.780 | 1.630
3.3 |  | 3.3x1.3 | 3.3x1.3 | 1.3 | 6g | 3.300 | 3.120 | 2.795 | 2.665 | 2.290 | 2.210
3.3 |  | ST3.3x1.3 | ST3.3x1.3 | 1.3 | 6g | 3.300 | 3.120 | 2.795 | 2.665 | 2.290 | 2.210
3.5 |  | 3.5x1.3 | 3.5x1.3 | 1.3 | 6g | 3.530 | 3.350 | 3.085 | 2.930 | 2.640 | 2.510
3.5 |  | ST3.5x1.3 | ST3.5x1.3 | 1.3 | 6g | 3.530 | 3.350 | 3.085 | 2.930 | 2.640 | 2.510
3.5 |  | 3.5x1.6 | 3.5x1.6 | 1.6 | 6g | 3.530 | 3.350 | 2.920 | 2.755 | 2.310 | 2.160
3.5 |  | 3.5x3.2 | 3.5x3.2 | 3.2 | 6g | 3.530 | 3.310 | 2.800 | 2.600 | 2.070 | 1.890
3.9 |  | 3.9x1.3 | 3.9x1.3 | 1.3 | 6g | 3.910 | 3.730 | 3.415 | 3.250 | 2.920 | 2.770
3.9 |  | ST3.9x1.3 | ST3.9x1.3 | 1.3 | 6g | 3.910 | 3.730 | 3.415 | 3.250 | 2.920 | 2.770
3.9 |  | 3.9x1.6 | 3.9x1.6 | 1.6 | 6g | 3.910 | 3.730 | 3.300 | 3.135 | 2.690 | 2.540
3.9 |  | 3.9x3.2 | 3.9x3.2 | 3.2 | 6g | 3.910 | 3.690 | 3.180 | 2.980 | 2.450 | 2.270
4.2 |  | 4.2x1.4 | 4.2x1.4 | 1.4 | 6g | 4.220 | 4.040 | 3.660 | 3.495 | 3.100 | 2.950
4.2 |  | ST4.2x1.4 | ST4.2x1.4 | 1.4 | 6g | 4.220 | 4.040 | 3.660 | 3.495 | 3.100 | 2.950
4.2 |  | 4.2x1.6 | 4.2x1.6 | 1.6 | 6g | 4.220 | 4.040 | 3.610 | 3.445 | 3.000 | 2.850
4.2 |  | 4.2x3.2 | 4.2x3.2 | 3.2 | 6g | 4.220 | 4.000 | 3.380 | 3.180 | 2.540 | 2.360
4.8 |  | 4.8x1.6 | 4.8x1.6 | 1.6 | 6g | 4.800 | 4.620 | 4.190 | 4.025 | 3.580 | 3.430
4.8 |  | ST4.8x1.6 | ST4.8x1.6 | 1.6 | 6g | 4.800 | 4.620 | 4.190 | 4.025 | 3.580 | 3.430
4.8 |  | 4.8x1.8 | 4.8x1.8 | 1.8 | 6g | 4.800 | 4.620 | 4.065 | 3.885 | 3.330 | 3.150
4.8 |  | 4.8x3.2 | 4.8x3.2 | 3.2 | 6g | 4.800 | 4.580 | 3.960 | 3.760 | 3.120 | 2.940
5.5 |  | 5.5x1.8 | 5.5x1.8 | 1.8 | 6g | 5.460 | 5.280 | 4.815 | 4.635 | 4.170 | 3.990
5.5 |  | ST5.5x1.8 | ST5.5x1.8 | 1.8 | 6g | 5.460 | 5.280 | 4.815 | 4.635 | 4.170 | 3.990
6.3 |  | 6.3x1.8 | 6.3x1.8 | 1.8 | 6g | 6.250 | 6.030 | 5.565 | 5.365 | 4.880 | 4.700
6.3 |  | ST6.3x1.8 | ST6.3x1.8 | 1.8 | 6g | 6.250 | 6.030 | 5.565 | 5.365 | 4.880 | 4.700
8.0 |  | 8x2.1 | 8x2.1 | 2.1 | 6g | 8.000 | 7.780 | 7.100 | 6.885 | 6.200 | 5.990
8.0 |  | ST8x2.1 | ST8x2.1 | 2.1 | 6g | 8.000 | 7.780 | 7.100 | 6.885 | 6.200 | 5.990
9.5 |  | 9.5x2.1 | 9.5x2.1 | 2.1 | 6g | 9.650 | 9.430 | 8.750 | 8.510 | 7.850 | 7.590
9.5 |  | ST9.5x2.1 | ST9.5x2.1 | 2.1 | 6g | 9.650 | 9.430 | 8.750 | 8.510 | 7.850 | 7.590

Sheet: ISO Pipe Threads
M Q | ISO Pipe Threads |  | Sort Order - 9 |  | External |  |  |  |  |  |  | Internal
 |  |  |  |  |  | Major Dia |  | Pitch Dia |  | Minor Dia |  |  | Minor Dia |  | Pitch Dia |  | Major Dia |  | Tap Drill | Thread Depth | Thread Runouts
Size | Size Suffix | Thread Designation | Custom Thread Designation | TPI | Class | Max | Min | Max | Min | Max | Min | Class | Min | Max | Min | Max | Min | Max | Basic
7.723 |  | G7.723x0.907 | G 1/16 | 28 | A | 7.723 | 7.509 | 7.142 | 7.035 | 6.561 |  |  | 6.561 | 6.834 | 7.142 | 7.249 | 7.723 |  | 1.5875 | 15.446 | 4.5000
7.723 |  | G7.723x0.907 | G 1/16 | 28 | B | 7.723 | 7.509 | 7.142 | 6.928 | 6.561
9.728 |  | G9.728x0.907 | G 1/8 | 28 | A | 9.728 | 9.514 | 9.147 | 9.040 | 8.566 |  |  | 8.566 | 8.848 | 9.147 | 9.254 | 9.728 |  | 3.1750 | 19.456 | 4.5000
9.728 |  | G9.728x0.907 | G 1/8 | 28 | B | 9.728 | 9.514 | 9.147 | 8.933 | 8.566
13.157 |  | G13.157x1.337 | G 1/4 | 19 | A | 13.157 | 12.907 | 12.301 | 12.176 | 11.445 |  |  | 11.445 | 11.89 | 12.301 | 12.426 | 13.157 |  | 6.3500 | 26.314 | 6.5000
13.157 |  | G13.157x1.337 | G 1/4 | 19 | B | 13.157 | 12.907 | 12.301 | 12.051 | 11.445
16.662 |  | G16.662x1.337 | G 3/8 | 19 | A | 16.662 | 16.412 | 15.806 | 15.681 | 14.950 |  |  | 14.95 | 15.395 | 15.806 | 15.931 | 16.662 |  | 9.5250 | 33.324 | 6.5000
16.662 |  | G16.662x1.337 | G 3/8 | 19 | B | 16.662 | 16.412 | 15.806 | 15.556 | 14.950
20.955 |  | G20.955x1.814 | G 1/2 | 14 | A | 20.955 | 20.671 | 19.793 | 19.651 | 18.631 |  |  | 18.631 | 19.172 | 19.793 | 19.935 | 20.955 |  | 12.7000 | 41.910 | 8.5000
20.955 |  | G20.955x1.814 | G 1/2 | 14 | B | 20.955 | 20.671 | 19.793 | 19.509 | 18.631
22.911 |  | G22.911x1.814 | G 5/8 | 14 | A | 22.911 | 22.627 | 21.749 | 21.607 | 20.587 |  |  | 20.587 | 21.128 | 21.749 | 21.891 | 22.911 |  |  | 45.822 | 8.5000
22.911 |  | G22.911x1.814 | G 5/8 | 14 | B | 22.911 | 22.627 | 21.749 | 21.465 | 20.587
26.441 |  | G26.441x1.814 | G 3/4 | 14 | A | 26.441 | 26.157 | 25.279 | 25.137 | 24.117 |  |  | 24.117 | 24.658 | 25.279 | 25.421 | 26.441 |  | 15.8750 | 52.882 | 8.5000
26.441 |  | G26.441x1.814 | G 3/4 | 14 | B | 26.441 | 26.157 | 25.279 | 24.995 | 24.117
30.201 |  | G30.201x1.814 | G 7/8 | 14 | A | 30.201 | 29.917 | 29.039 | 28.897 | 27.877 |  |  | 27.877 | 28.418 | 29.039 | 29.181 | 30.201 |  | 22.2250 | 60.402 | 8.5000
30.201 |  | G30.201x1.814 | G 7/8 | 14 | B | 30.201 | 29.917 | 29.039 | 28.755 | 27.877
33.249 |  | G33.249x2.309 | G 1 | 11 | A | 33.249 | 32.889 | 31.770 | 31.590 | 30.291 |  |  | 30.291 | 30.931 | 31.77 | 31.95 | 33.249 |  | 25.4000 | 66.498 | 10.0000
33.249 |  | G33.249x2.309 | G 1 | 11 | B | 33.249 | 32.889 | 31.770 | 31.410 | 30.291
37.897 |  | G37.897x2.309 | G 1 1/8 | 11 | A | 37.897 | 37.537 | 36.418 | 36.238 | 34.939 |  |  | 34.939 | 35.579 | 36.418 | 36.598 | 37.897 |  | 28.5750 | 75.794 | 10.0000
37.897 |  | G37.897x2.309 | G 1 1/8 | 11 | B | 37.897 | 37.537 | 36.418 | 36.058 | 34.939
41.910 |  | G41.91x2.309 | G 1 1/4 | 11 | A | 41.910 | 41.550 | 40.431 | 40.251 | 38.952 |  |  | 38.952 | 39.592 | 40.431 | 40.611 | 41.910 |  | 31.7500 | 83.820 | 10.0000
41.910 |  | G41.91x2.309 | G 1 1/4 | 11 | B | 41.910 | 41.550 | 40.431 | 40.071 | 38.952
47.803 |  | G47.803x2.309 | G 1 1/2 | 11 | A | 47.803 | 47.443 | 46.324 | 46.144 | 44.845 |  |  | 44.845 | 45.485 | 46.324 | 46.504 | 47.803 |  | 38.1000 | 95.606 | 10.0000
47.803 |  | G47.803x2.309 | G 1 1/2 | 11 | B | 47.803 | 47.443 | 46.324 | 45.964 | 44.845
53.746 |  | G53.746x2.309 | G 1 3/4 | 11 | A | 53.746 | 53.386 | 52.267 | 52.087 | 50.788 |  |  | 50.788 | 51.428 | 52.267 | 52.447 | 53.746 |  | 44.4500 | 107.492 | 10.0000
53.746 |  | G53.746x2.309 | G 1 3/4 | 11 | B | 53.746 | 53.386 | 52.267 | 51.907 | 50.788
59.614 |  | G59.614x2.309 | G 2 | 11 | A | 59.614 | 59.254 | 58.135 | 57.955 | 56.656 |  |  | 56.656 | 57.296 | 58.135 | 58.315 | 59.614 |  | 50.8000 | 119.228 | 10.0000
59.614 |  | G59.614x2.309 | G 2 | 11 | B | 59.614 | 59.254 | 58.135 | 57.775 | 56.656
65.710 |  | G65.71x2.309 | G 2 1/4 | 11 | A | 65.710 | 65.276 | 64.231 | 64.014 | 62.752 |  |  | 62.752 | 63.392 | 64.231 | 64.448 | 65.710 |  | 57.1500 | 131.420 | 10.0000
65.710 |  | G65.71x2.309 | G 2 1/4 | 11 | B | 65.710 | 65.276 | 64.231 | 63.797 | 62.752
75.184 |  | G75.184x2.309 | G 2 1/2 | 11 | A | 75.184 | 74.750 | 73.705 | 73.488 | 72.226 |  |  | 72.226 | 72.866 | 73.705 | 73.922 | 75.184 |  |  | 150.368 | 10.0000
75.184 |  | G75.184x2.309 | G 2 1/2 | 11 | B | 75.184 | 74.750 | 73.705 | 73.271 | 72.226
81.534 |  | G81.534x2.309 | G 2 3/4 | 11 | A | 81.534 | 81.100 | 80.055 | 79.838 | 78.576 |  |  | 78.576 | 79.216 | 80.055 | 80.272 | 81.534 |  | 69.8500 | 163.068 | 10.0000
81.534 |  | G81.534x2.309 | G 2 3/4 | 11 | B | 81.534 | 81.100 | 80.055 | 79.621 | 78.576
87.884 |  | G87.884x2.309 | G 3 | 11 | A | 87.884 | 87.450 | 86.405 | 86.188 | 84.926 |  |  | 84.926 | 85.566 | 86.405 | 86.622 | 87.884 |  | 76.2000 | 175.768 | 10.0000
87.884 |  | G87.884x2.309 | G 3 | 11 | B | 87.884 | 87.450 | 86.405 | 85.971 | 84.926
100.330 |  | G100.33x2.309 | G 3 1/2 | 11 | A | 100.330 | 99.896 | 98.851 | 98.634 | 97.372 |  |  | 97.372 | 98.012 | 98.851 | 99.068 | 100.330 |  | 88.9000 | 200.660 | 10.0000
100.330 |  | G100.33x2.309 | G 3 1/2 | 11 | B | 100.330 | 99.896 | 98.851 | 98.417 | 97.372
113.030 |  | G113.03x2.309 | G 4 | 11 | A | 113.030 | 112.596 | 111.551 | 111.334 | 110.072 |  |  | 110.072 | 110.712 | 111.551 | 111.768 | 113.030 |  | 101.6000 | 226.060 | 10.0000
113.030 |  | G113.03x2.309 | G 4 | 11 | B | 113.030 | 112.596 | 111.551 | 111.117 | 110.072
125.730 |  | G125.73x2.309 | G 4 1/2 | 11 | A | 125.730 | 125.296 | 124.251 | 124.034 | 122.772 |  |  | 122.772 | 123.412 | 124.251 | 124.468 | 125.730 |  | 114.3000 | 251.460 | 10.0000
125.730 |  | G125.73x2.309 | G 4 1/2 | 11 | B | 125.730 | 125.296 | 124.251 | 123.817 | 122.772
138.430 |  | G138.43x2.309 | G 5 | 11 | A | 138.430 | 137.996 | 136.951 | 136.734 | 135.472 |  |  | 135.472 | 136.112 | 136.951 | 137.168 | 138.430 |  | 127.0000 | 276.860 | 10.0000
138.430 |  | G138.43x2.309 | G 5 | 11 | B | 138.430 | 137.996 | 136.951 | 136.517 | 135.472
151.130 |  | G151.13x2.309 | G 5 1/2 | 11 | A | 151.130 | 150.696 | 149.651 | 149.434 | 148.172 |  |  | 148.172 | 148.812 | 149.651 | 149.868 | 151.130 |  | 139.7000 | 302.260 | 10.0000
151.130 |  | G151.13x2.309 | G 5 1/2 | 11 | B | 151.130 | 150.696 | 149.651 | 149.217 | 148.172
163.830 |  | G163.83x2.309 | G 6 | 11 | A | 163.830 | 163.396 | 162.351 | 162.134 | 160.872 |  |  | 160.872 | 161.512 | 162.351 | 162.568 | 163.830 |  | 152.4000 | 327.660 | 10.0000
163.830 |  | G163.83x2.309 | G 6 | 11 | B | 163.830 | 163.396 | 162.351 | 161.917 | 160.872

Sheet: JIS Pipe Threads
M Q | JIS Pipe Threads |  | Sort Order -12 |  | External |  |  |  |  |  |  | Internal
 |  |  |  |  |  | Major Dia |  | Pitch Dia |  | Minor Dia |  |  | Minor Dia |  | Pitch Dia |  | Major Dia |  | Tap Drill | Thread Depth | Thread Runouts
Size | Size Suffix | Thread Designation | Custom Thread Designation | TPI | Class | Max | Min | Max | Min | Max | Min | Class | Min | Max | Min | Max | Min | Max | Basic |  | Basic
7.723 |  | G7.723x0.907 | G 1/16 | 28 | A | 7.723 | 7.509 | 7.142 | 7.035 | 6.561 |  |  | 6.561 | 6.834 | 7.142 | 7.249 | 7.723 |  | 1.5875 | 15.446 | 4.5000
7.723 |  | G7.723x0.907 | G 1/16 | 28 | B | 7.723 | 7.509 | 7.142 | 6.928 | 6.561
9.728 |  | G9.728x0.907 | G 1/8 | 28 | A | 9.728 | 9.514 | 9.147 | 9.040 | 8.566 |  |  | 8.566 | 8.848 | 9.147 | 9.254 | 9.728 |  | 3.1750 | 19.456 | 4.5000
9.728 |  | G9.728x0.907 | G 1/8 | 28 | B | 9.728 | 9.514 | 9.147 | 8.933 | 8.566
13.157 |  | G13.157x1.337 | G 1/4 | 19 | A | 13.157 | 12.907 | 12.301 | 12.176 | 11.445 |  |  | 11.445 | 11.89 | 12.301 | 12.426 | 13.157 |  | 6.3500 | 26.314 | 6.5000
13.157 |  | G13.157x1.337 | G 1/4 | 19 | B | 13.157 | 12.907 | 12.301 | 12.051 | 11.445
16.662 |  | G16.662x1.337 | G 3/8 | 19 | A | 16.662 | 16.412 | 15.806 | 15.681 | 14.950 |  |  | 14.95 | 15.395 | 15.806 | 15.931 | 16.662 |  | 9.5250 | 33.324 | 6.5000
16.662 |  | G16.662x1.337 | G 3/8 | 19 | B | 16.662 | 16.412 | 15.806 | 15.556 | 14.950
20.955 |  | G20.955x1.814 | G 1/2 | 14 | A | 20.955 | 20.671 | 19.793 | 19.651 | 18.631 |  |  | 18.631 | 19.172 | 19.793 | 19.935 | 20.955 |  | 12.7000 | 41.910 | 8.5000
20.955 |  | G20.955x1.814 | G 1/2 | 14 | B | 20.955 | 20.671 | 19.793 | 19.509 | 18.631
22.911 |  | G22.911x1.814 | G 5/8 | 14 | A | 22.911 | 22.627 | 21.749 | 21.607 | 20.587 |  |  | 20.587 | 21.128 | 21.749 | 21.891 | 22.911 |  |  | 45.822 | 8.5000
22.911 |  | G22.911x1.814 | G 5/8 | 14 | B | 22.911 | 22.627 | 21.749 | 21.465 | 20.587
26.441 |  | G26.441x1.814 | G 3/4 | 14 | A | 26.441 | 26.157 | 25.279 | 25.137 | 24.117 |  |  | 24.117 | 24.658 | 25.279 | 25.421 | 26.441 |  | 15.8750 | 52.882 | 8.5000
26.441 |  | G26.441x1.814 | G 3/4 | 14 | B | 26.441 | 26.157 | 25.279 | 24.995 | 24.117
30.201 |  | G30.201x1.814 | G 7/8 | 14 | A | 30.201 | 29.917 | 29.039 | 28.897 | 27.877 |  |  | 27.877 | 28.418 | 29.039 | 29.181 | 30.201 |  | 22.2250 | 60.402 | 8.8000
30.201 |  | G30.201x1.814 | G 7/8 | 14 | B | 30.201 | 29.917 | 29.039 | 28.755 | 27.877
33.249 |  | G33.249x2.309 | G 1 | 11 | A | 33.249 | 32.889 | 31.770 | 31.590 | 30.291 |  |  | 30.291 | 30.931 | 31.77 | 31.95 | 33.249 |  | 25.4000 | 66.498 | 10.0000
33.249 |  | G33.249x2.309 | G 1 | 11 | B | 33.249 | 32.889 | 31.770 | 31.410 | 30.291
37.897 |  | G37.897x2.309 | G 1 1/8 | 11 | A | 37.897 | 37.537 | 36.418 | 36.238 | 34.939 |  |  | 34.939 | 35.579 | 36.418 | 36.598 | 37.897 |  | 28.5750 | 75.794 | 10.0000
37.897 |  | G37.897x2.309 | G 1 1/8 | 11 | B | 37.897 | 37.537 | 36.418 | 36.058 | 34.939
41.910 |  | G41.91x2.309 | G 1 1/4 | 11 | A | 41.910 | 41.550 | 40.431 | 40.251 | 38.952 |  |  | 38.952 | 39.592 | 40.431 | 40.611 | 41.910 |  | 31.7500 | 83.820 | 10.0000
41.910 |  | G41.91x2.309 | G 1 1/4 | 11 | B | 41.910 | 41.550 | 40.431 | 40.071 | 38.952
47.803 |  | G47.803x2.309 | G 1 1/2 | 11 | A | 47.803 | 47.443 | 46.324 | 46.144 | 44.845 |  |  | 44.845 | 45.485 | 46.324 | 46.504 | 47.803 |  | 38.1000 | 95.606 | 10.0000
47.803 |  | G47.803x2.309 | G 1 1/2 | 11 | B | 47.803 | 47.443 | 46.324 | 45.964 | 44.845
53.746 |  | G53.746x2.309 | G 1 3/4 | 11 | A | 53.746 | 53.386 | 52.267 | 52.087 | 50.788 |  |  | 50.788 | 51.428 | 52.267 | 52.447 | 53.746 |  | 44.4500 | 107.492 | 10.0000
53.746 |  | G53.746x2.309 | G 1 3/4 | 11 | B | 53.746 | 53.386 | 52.267 | 51.907 | 50.788
59.614 |  | G59.614x2.309 | G 2 | 11 | A | 59.614 | 59.254 | 58.135 | 57.955 | 56.656 |  |  | 56.656 | 57.296 | 58.135 | 58.315 | 59.614 |  | 50.8000 | 119.228 | 10.0000
59.614 |  | G59.614x2.309 | G 2 | 11 | B | 59.614 | 59.254 | 58.135 | 57.775 | 56.656
65.710 |  | G65.71x2.309 | G 2 1/4 | 11 | A | 65.710 | 65.276 | 64.231 | 64.014 | 62.752 |  |  | 62.752 | 63.392 | 64.231 | 64.448 | 65.710 |  | 57.1500 | 131.420 | 10.0000
65.710 |  | G65.71x2.309 | G 2 1/4 | 11 | B | 65.710 | 65.276 | 64.231 | 63.797 | 62.752
75.184 |  | G75.184x2.309 | G 2 1/2 | 11 | A | 75.184 | 74.750 | 73.705 | 73.488 | 72.226 |  |  | 72.226 | 72.866 | 73.705 | 73.922 | 75.184 |  |  | 150.368 | 10.0000
75.184 |  | G75.184x2.309 | G 2 1/2 | 11 | B | 75.184 | 74.750 | 73.705 | 73.271 | 72.226
81.534 |  | G81.534x2.309 | G 2 3/4 | 11 | A | 81.534 | 81.100 | 80.055 | 79.838 | 78.576 |  |  | 78.576 | 79.216 | 80.055 | 80.272 | 81.534 |  | 69.8500 | 163.068 | 10.0000
81.534 |  | G81.534x2.309 | G 2 3/4 | 11 | B | 81.534 | 81.100 | 80.055 | 79.621 | 78.576
87.884 |  | G87.884x2.309 | G 3 | 11 | A | 87.884 | 87.450 | 86.405 | 86.188 | 84.926 |  |  | 84.926 | 85.566 | 86.405 | 86.622 | 87.884 |  | 76.2000 | 175.768 | 10.0000
87.884 |  | G87.884x2.309 | G 3 | 11 | B | 87.884 | 87.450 | 86.405 | 85.971 | 84.926
100.330 |  | G100.33x2.309 | G 3 1/2 | 11 | A | 100.330 | 99.896 | 98.851 | 98.634 | 97.372 |  |  | 97.372 | 98.012 | 98.851 | 99.068 | 100.330 |  | 88.9000 | 200.660 | 10.0000
100.330 |  | G100.33x2.309 | G 3 1/2 | 11 | B | 100.330 | 99.896 | 98.851 | 98.417 | 97.372
113.030 |  | G113.03x2.309 | G 4 | 11 | A | 113.030 | 112.596 | 111.551 | 111.334 | 110.072 |  |  | 110.072 | 110.712 | 111.551 | 111.768 | 113.030 |  | 101.6000 | 226.060 | 10.0000
113.030 |  | G113.03x2.309 | G 4 | 11 | B | 113.030 | 112.596 | 111.551 | 111.117 | 110.072
125.730 |  | G125.73x2.309 | G 4 1/2 | 11 | A | 125.730 | 125.296 | 124.251 | 124.034 | 122.772 |  |  | 122.772 | 123.412 | 124.251 | 124.468 | 125.730 |  | 114.3000 | 251.460 | 10.0000
125.730 |  | G125.73x2.309 | G 4 1/2 | 11 | B | 125.730 | 125.296 | 124.251 | 123.817 | 122.772
138.430 |  | G138.43x2.309 | G 5 | 11 | A | 138.430 | 137.996 | 136.951 | 136.734 | 135.472 |  |  | 135.472 | 136.112 | 136.951 | 137.168 | 138.430 |  | 127.0000 | 276.860 | 10.0000
138.430 |  | G138.43x2.309 | G 5 | 11 | B | 138.430 | 137.996 | 136.951 | 136.517 | 135.472
151.130 |  | G151.13x2.309 | G 5 1/2 | 11 | A | 151.130 | 150.696 | 149.651 | 149.434 | 148.172 |  |  | 148.172 | 148.812 | 149.651 | 149.868 | 151.130 |  | 139.7000 | 302.260 | 10.0000
151.130 |  | G151.13x2.309 | G 5 1/2 | 11 | B | 151.130 | 150.696 | 149.651 | 149.217 | 148.172
163.830 |  | G163.83x2.309 | G 6 | 11 | A | 163.830 | 163.396 | 162.351 | 162.134 | 160.872 |  |  | 160.872 | 161.512 | 162.351 | 162.568 | 163.830 |  | 152.4000 | 327.660 | 10.0000
163.830 |  | G163.83x2.309 | G 6 | 11 | B | 163.830 | 163.396 | 162.351 | 161.917 | 160.872

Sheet: DIN Pipe Threads
M Q | DIN Pipe Threads |  | Sort Order - 18 |  | External |  |  |  |  |  |  | Internal
 |  |  |  |  |  | Major Dia |  | Pitch Dia |  | Minor Dia |  |  | Minor Dia |  | Pitch Dia |  | Major Dia |  | Tap Drill | Thread Depth | Thread Runouts
Size | Size Suffix | Thread Designation | Custom Thread Designation | TPI | Class | Max | Min | Max | Min | Max | Min | Class | Min | Max | Min | Max | Min | Max | Basic
7.723 |  | G7.723x0.907 | G 1/16 | 28 | A | 7.723 | 7.509 | 7.142 | 7.035 | 6.561 |  |  | 6.561 | 6.834 | 7.142 | 7.249 | 7.723 |  | 1.5875 | 15.446 | 4.5000
7.723 |  | G7.723x0.907 | G 1/16 | 28 | B | 7.723 | 7.509 | 7.142 | 6.928 | 6.561
9.728 |  | G9.728x0.907 | G 1/8 | 28 | A | 9.728 | 9.514 | 9.147 | 9.040 | 8.566 |  |  | 8.566 | 8.848 | 9.147 | 9.254 | 9.728 |  | 3.1750 | 19.456 | 4.5000
9.728 |  | G9.728x0.907 | G 1/8 | 28 | B | 9.728 | 9.514 | 9.147 | 8.933 | 8.566
13.157 |  | G13.157x1.337 | G 1/4 | 19 | A | 13.157 | 12.907 | 12.301 | 12.176 | 11.445 |  |  | 11.445 | 11.89 | 12.301 | 12.426 | 13.157 |  | 6.3500 | 26.314 | 6.5000
13.157 |  | G13.157x1.337 | G 1/4 | 19 | B | 13.157 | 12.907 | 12.301 | 12.051 | 11.445
16.662 |  | G16.662x1.337 | G 3/8 | 19 | A | 16.662 | 16.412 | 15.806 | 15.681 | 14.950 |  |  | 14.95 | 15.395 | 15.806 | 15.931 | 16.662 |  | 9.5250 | 33.324 | 6.5000
16.662 |  | G16.662x1.337 | G 3/8 | 19 | B | 16.662 | 16.412 | 15.806 | 15.556 | 14.950
20.955 |  | G20.955x1.814 | G 1/2 | 14 | A | 20.955 | 20.671 | 19.793 | 19.651 | 18.631 |  |  | 18.631 | 19.172 | 19.793 | 19.935 | 20.955 |  | 12.7000 | 41.910 | 8.5000
20.955 |  | G20.955x1.814 | G 1/2 | 14 | B | 20.955 | 20.671 | 19.793 | 19.509 | 18.631
22.911 |  | G22.911x1.814 | G 5/8 | 14 | A | 22.911 | 22.627 | 21.749 | 21.607 | 20.587 |  |  | 20.587 | 21.128 | 21.749 | 21.891 | 22.911 |  |  | 45.822 | 8.5000
22.911 |  | G22.911x1.814 | G 5/8 | 14 | B | 22.911 | 22.627 | 21.749 | 21.465 | 20.587
26.441 |  | G26.441x1.814 | G 3/4 | 14 | A | 26.441 | 26.157 | 25.279 | 25.137 | 24.117 |  |  | 24.117 | 24.658 | 25.279 | 25.421 | 26.441 |  | 15.8750 | 52.882 | 8.5000
26.441 |  | G26.441x1.814 | G 3/4 | 14 | B | 26.441 | 26.157 | 25.279 | 24.995 | 24.117
30.201 |  | G30.201x1.814 | G 7/8 | 14 | A | 30.201 | 29.917 | 29.039 | 28.897 | 27.877 |  |  | 27.877 | 28.418 | 29.039 | 29.181 | 30.201 |  | 22.2250 | 60.402 | 8.5000
30.201 |  | G30.201x1.814 | G 7/8 | 14 | B | 30.201 | 29.917 | 29.039 | 28.755 | 27.877
33.249 |  | G33.249x2.309 | G 1 | 11 | A | 33.249 | 32.889 | 31.770 | 31.590 | 30.291 |  |  | 30.291 | 30.931 | 31.77 | 31.95 | 33.249 |  | 25.4000 | 66.498 | 10.5000
33.249 |  | G33.249x2.309 | G 1 | 11 | B | 33.249 | 32.889 | 31.770 | 31.410 | 30.291
37.897 |  | G37.897x2.309 | G 1 1/8 | 11 | A | 37.897 | 37.537 | 36.418 | 36.238 | 34.939 |  |  | 34.939 | 35.579 | 36.418 | 36.598 | 37.897 |  | 28.5750 | 75.794 | 10.5000
37.897 |  | G37.897x2.309 | G 1 1/8 | 11 | B | 37.897 | 37.537 | 36.418 | 36.058 | 34.939
41.910 |  | G41.91x2.309 | G 1 1/4 | 11 | A | 41.910 | 41.550 | 40.431 | 40.251 | 38.952 |  |  | 38.952 | 39.592 | 40.431 | 40.611 | 41.910 |  | 31.7500 | 83.820 | 10.5000
41.910 |  | G41.91x2.309 | G 1 1/4 | 11 | B | 41.910 | 41.550 | 40.431 | 40.071 | 38.952
47.803 |  | G47.803x2.309 | G 1 1/2 | 11 | A | 47.803 | 47.443 | 46.324 | 46.144 | 44.845 |  |  | 44.845 | 45.485 | 46.324 | 46.504 | 47.803 |  | 38.1000 | 95.606 | 10.5000
47.803 |  | G47.803x2.309 | G 1 1/2 | 11 | B | 47.803 | 47.443 | 46.324 | 45.964 | 44.845
53.746 |  | G53.746x2.309 | G 1 3/4 | 11 | A | 53.746 | 53.386 | 52.267 | 52.087 | 50.788 |  |  | 50.788 | 51.428 | 52.267 | 52.447 | 53.746 |  | 44.4500 | 107.492 | 10.5000
53.746 |  | G53.746x2.309 | G 1 3/4 | 11 | B | 53.746 | 53.386 | 52.267 | 51.907 | 50.788
59.614 |  | G59.614x2.309 | G 2 | 11 | A | 59.614 | 59.254 | 58.135 | 57.955 | 56.656 |  |  | 56.656 | 57.296 | 58.135 | 58.315 | 59.614 |  | 50.8000 | 119.228 | 10.5000
59.614 |  | G59.614x2.309 | G 2 | 11 | B | 59.614 | 59.254 | 58.135 | 57.775 | 56.656
65.710 |  | G65.71x2.309 | G 2 1/4 | 11 | A | 65.710 | 65.276 | 64.231 | 64.014 | 62.752 |  |  | 62.752 | 63.392 | 64.231 | 64.448 | 65.710 |  | 57.1500 | 131.420 | 10.5000
65.710 |  | G65.71x2.309 | G 2 1/4 | 11 | B | 65.710 | 65.276 | 64.231 | 63.797 | 62.752
75.184 |  | G75.184x2.309 | G 2 1/2 | 11 | A | 75.184 | 74.750 | 73.705 | 73.488 | 72.226 |  |  | 72.226 | 72.866 | 73.705 | 73.922 | 75.184 |  |  | 150.368 | 10.5000
75.184 |  | G75.184x2.309 | G 2 1/2 | 11 | B | 75.184 | 74.750 | 73.705 | 73.271 | 72.226
81.534 |  | G81.534x2.309 | G 2 3/4 | 11 | A | 81.534 | 81.100 | 80.055 | 79.838 | 78.576 |  |  | 78.576 | 79.216 | 80.055 | 80.272 | 81.534 |  | 69.8500 | 163.068 | 10.5000
81.534 |  | G81.534x2.309 | G 2 3/4 | 11 | B | 81.534 | 81.100 | 80.055 | 79.621 | 78.576
87.884 |  | G87.884x2.309 | G 3 | 11 | A | 87.884 | 87.450 | 86.405 | 86.188 | 84.926 |  |  | 84.926 | 85.566 | 86.405 | 86.622 | 87.884 |  | 76.2000 | 175.768 | 10.5000
87.884 |  | G87.884x2.309 | G 3 | 11 | B | 87.884 | 87.450 | 86.405 | 85.971 | 84.926
100.330 |  | G100.33x2.309 | G 3 1/2 | 11 | A | 100.330 | 99.896 | 98.851 | 98.634 | 97.372 |  |  | 97.372 | 98.012 | 98.851 | 99.068 | 100.330 |  | 88.9000 | 200.660 | 10.5000
100.330 |  | G100.33x2.309 | G 3 1/2 | 11 | B | 100.330 | 99.896 | 98.851 | 98.417 | 97.372
113.030 |  | G113.03x2.309 | G 4 | 11 | A | 113.030 | 112.596 | 111.551 | 111.334 | 110.072 |  |  | 110.072 | 110.712 | 111.551 | 111.768 | 113.030 |  | 101.6000 | 226.060 | 10.5000
113.030 |  | G113.03x2.309 | G 4 | 11 | B | 113.030 | 112.596 | 111.551 | 111.117 | 110.072
125.730 |  | G125.73x2.309 | G 4 1/2 | 11 | A | 125.730 | 125.296 | 124.251 | 124.034 | 122.772 |  |  | 122.772 | 123.412 | 124.251 | 124.468 | 125.730 |  | 114.3000 | 251.460 | 10.5000
125.730 |  | G125.73x2.309 | G 4 1/2 | 11 | B | 125.730 | 125.296 | 124.251 | 123.817 | 122.772
138.430 |  | G138.43x2.309 | G 5 | 11 | A | 138.430 | 137.996 | 136.951 | 136.734 | 135.472 |  |  | 135.472 | 136.112 | 136.951 | 137.168 | 138.430 |  | 127.0000 | 276.860 | 10.5000
138.430 |  | G138.43x2.309 | G 5 | 11 | B | 138.430 | 137.996 | 136.951 | 136.517 | 135.472
151.130 |  | G151.13x2.309 | G 5 1/2 | 11 | A | 151.130 | 150.696 | 149.651 | 149.434 | 148.172 |  |  | 148.172 | 148.812 | 149.651 | 149.868 | 151.130 |  | 139.7000 | 302.260 | 10.5000
151.130 |  | G151.13x2.309 | G 5 1/2 | 11 | B | 151.130 | 150.696 | 149.651 | 149.217 | 148.172
163.830 |  | G163.83x2.309 | G 6 | 11 | A | 163.830 | 163.396 | 162.351 | 162.134 | 160.872 |  |  | 160.872 | 161.512 | 162.351 | 162.568 | 163.830 |  | 152.4000 | 327.660 | 10.5000
163.830 |  | G163.83x2.309 | G 6 | 11 | B | 163.830 | 163.396 | 162.351 | 161.917 | 160.872

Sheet: BSP Pipe Threads
M Q | BSP Pipe Threads |  | Sort Order - 19 |  | External |  |  |  |  |  |  | Internal
 |  |  |  |  |  | Major Dia |  | Pitch Dia |  | Minor Dia |  |  | Minor Dia |  | Pitch Dia |  | Major Dia |  | Tap Drill | Thread Depth | Thread Runouts
Size | Size Suffix | Thread Designation | Custom Thread Designation | TPI | Class | Max | Min | Max | Min | Max | Min | Class | Min | Max | Min | Max | Min | Max | Basic |  | Basic
1/16 |  | G 1/16-28 | G 1/16-28 | 28 | A | 7.723 | 7.509 | 7.142 | 7.035 | 6.561 |  |  | 6.561 | 6.834 | 7.142 | 7.249 | 7.723 |  | 6.6000 | 15.4460 | 4.5000
1/16 |  | G 1/16-28 | G 1/16-28 | 28 | B | 7.723 | 7.509 | 7.142 | 7.035 | 6.561
1/8 |  | G 1/8-28 | G 1/8-28 | 28 | A | 9.728 | 9.514 | 9.147 | 9.040 | 8.566 |  |  | 8.566 | 8.848 | 9.147 | 9.254 | 9.728 |  | 8.7300 | 19.4560 | 4.5000
1/8 |  | G 1/8-28 | G 1/8-28 | 28 | B | 9.728 | 9.514 | 9.147 | 9.040 | 8.566
1/4 |  | G 1/4-19 | G 1/4-19 | 19 | A | 13.157 | 12.907 | 12.301 | 12.176 | 11.445 |  |  | 11.445 | 11.89 | 12.301 | 12.426 | 13.157 |  | 11.8000 | 26.3140 | 6.5000
1/4 |  | G 1/4-19 | G 1/4-19 | 19 | B | 13.157 | 12.907 | 12.301 | 12.176 | 11.445
3/8 |  | G 3/8-19 | G 3/8-19 | 19 | A | 16.662 | 16.412 | 15.806 | 15.681 | 14.950 |  |  | 14.95 | 15.395 | 15.806 | 15.931 | 16.662 |  | 15.2500 | 33.3240 | 6.5000
3/8 |  | G 3/8-19 | G 3/8-19 | 19 | B | 16.662 | 16.412 | 15.806 | 15.681 | 14.950
1/2 |  | G 1/2-14 | G 1/2-14 | 14 | A | 20.955 | 20.671 | 19.793 | 19.651 | 18.631 |  |  | 18.631 | 19.172 | 19.793 | 19.935 | 20.955 |  | 19.0500 | 41.9100 | 8.5000
1/2 |  | G 1/2-14 | G 1/2-14 | 14 | B | 20.955 | 20.671 | 19.793 | 19.651 | 18.631
5/8 |  | G 5/8-14 | G 5/8-14 | 14 | A | 22.911 | 22.627 | 21.749 | 21.607 | 20.587 |  |  | 20.587 | 21.128 | 21.749 | 21.891 | 22.911 |  | 21.0000 | 45.8220 | 8.5000
5/8 |  | G 5/8-14 | G 5/8-14 | 14 | B | 22.911 | 22.627 | 21.749 | 21.607 | 20.587
3/4 |  | G 3/4-14 | G 3/4-14 | 14 | A | 26.441 | 26.157 | 25.279 | 25.137 | 24.117 |  |  | 24.117 | 24.658 | 25.279 | 25.421 | 26.441 |  | 24.5000 | 52.8820 | 8.5000
3/4 |  | G 3/4-14 | G 3/4-14 | 14 | B | 26.441 | 26.157 | 25.279 | 25.137 | 24.117
7/8 |  | G 7/8-14 | G 7/8-14 | 14 | A | 30.201 | 29.917 | 29.039 | 28.897 | 27.877 |  |  | 27.877 | 28.418 | 29.039 | 29.181 | 30.201 |  | 28.2500 | 60.4020 | 8.5000
7/8 |  | G 7/8-14 | G 7/8-14 | 14 | B | 30.201 | 29.917 | 29.039 | 28.897 | 27.877
1 |  | G 1-11 | G 1-11 | 11 | A | 33.249 | 32.889 | 31.770 | 31.590 | 30.291 |  |  | 30.291 | 30.931 | 31.77 | 31.95 | 33.249 |  | 30.7500 | 66.4980 | 10.0000
1 |  | G 1-11 | G 1-11 | 11 | B | 33.249 | 32.889 | 31.770 | 31.590 | 30.291
1 1/4 |  | G 1 1/4-11 | G 1 1/4-11 | 11 | A | 41.910 | 41.550 | 40.431 | 40.251 | 38.952 |  |  | 38.952 | 39.592 | 40.431 | 40.611 | 41.910 |  | 39.5000 | 83.8200 | 10.0000
1 1/4 |  | G 1 1/4-11 | G 1 1/4-11 | 11 | B | 41.910 | 41.550 | 40.431 | 40.251 | 38.952
1 1/2 |  | G 1 1/2-11 | G 1 1/2-11 | 11 | A | 47.803 | 47.443 | 46.324 | 46.144 | 44.845 |  |  | 44.845 | 45.485 | 46.324 | 46.504 | 47.803 |  | 45.5000 | 95.6060 | 10.0000
1 1/2 |  | G 1 1/2-11 | G 1 1/2-11 | 11 | B | 47.803 | 47.443 | 46.324 | 46.144 | 44.845
1 3/4 |  | G 1 3/4-11 | G 1 3/4-11 | 11 | A | 53.746 | 53.386 | 52.267 | 52.087 | 50.788 |  |  | 50.788 | 51.428 | 52.267 | 52.447 | 53.746 |  | 51.0000 | 107.4920 | 10.0000
1 3/4 |  | G 1 3/4-11 | G 1 3/4-11 | 11 | B | 53.746 | 53.386 | 52.267 | 52.087 | 50.788
2 |  | G 2-11 | G 2-11 | 11 | A | 59.614 | 59.254 | 58.135 | 57.955 | 56.656 |  |  | 56.656 | 57.296 | 58.135 | 58.315 | 59.614 |  | 57.0000 | 119.2280 | 10.0000
2 |  | G 2-11 | G 2-11 | 11 | B | 59.614 | 59.254 | 58.135 | 57.955 | 56.656
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

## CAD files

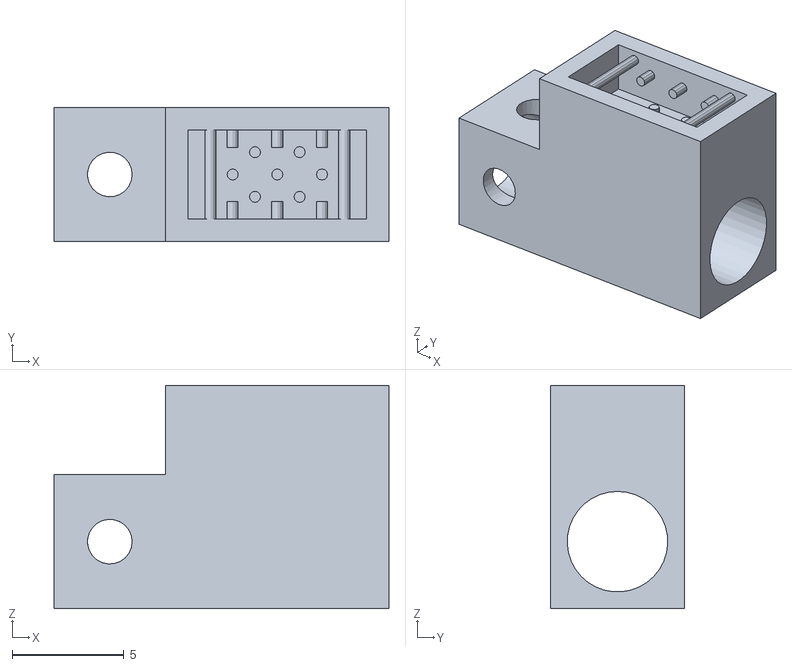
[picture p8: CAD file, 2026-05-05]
downloads/ASLM_CTASLM_Baseplate/Sample Holders/CollagenSampleHolder.stl
15.0 x 6.00 x 10.0

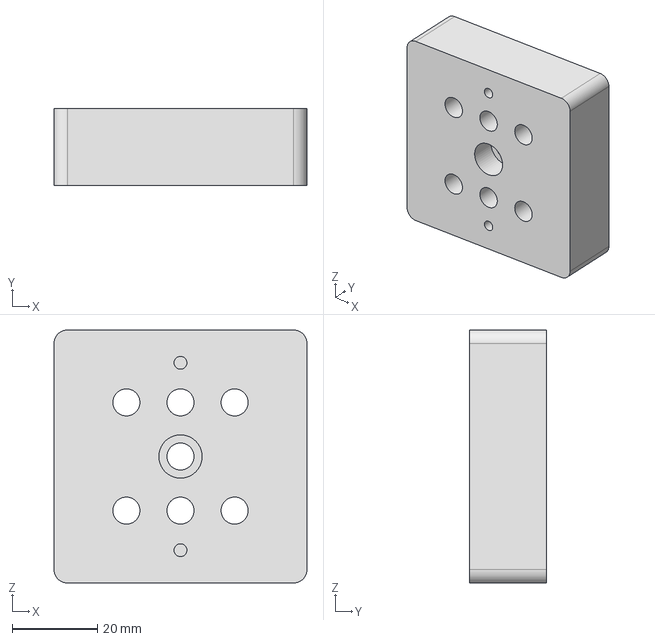
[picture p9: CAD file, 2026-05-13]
downloads/dvOPM/CAD/To Machine/LNR25MtoPolarisAdapter.stp
59.4 x 18.1 x 59.4 mm

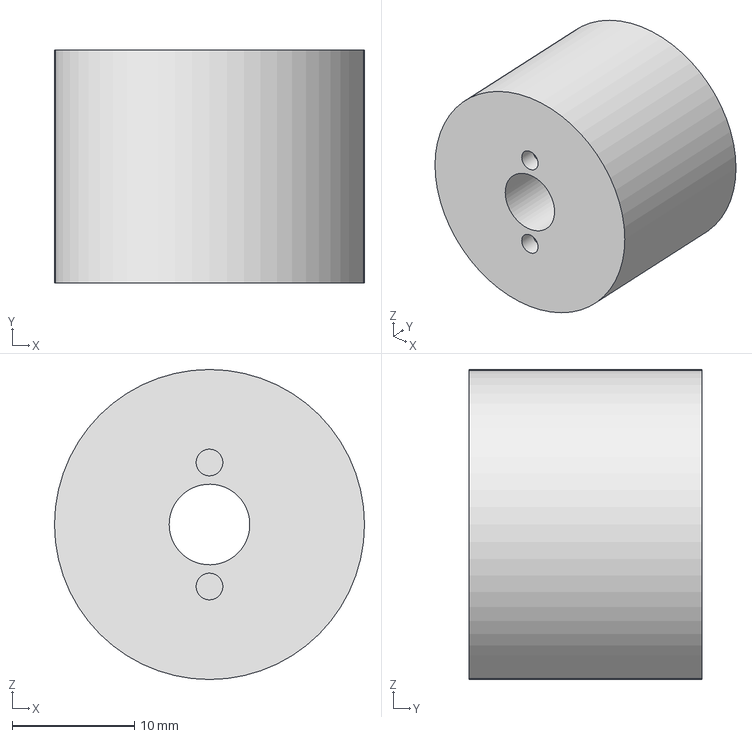
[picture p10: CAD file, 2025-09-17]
downloads/common/cad/45DegreeMirrorPost_0p75in.stp
25.4 x 19.0 x 25.4 mm

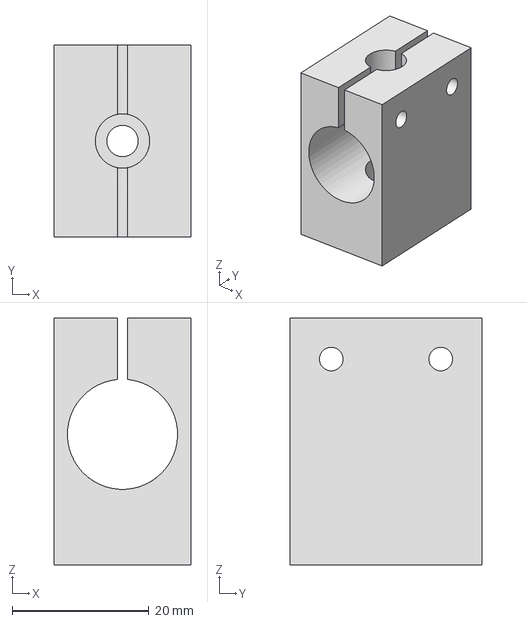
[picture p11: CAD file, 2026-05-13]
downloads/dvOPM/CAD/To Machine/GalvoHoldertoPolarisMount.stp
20.0 x 28.0 x 36.1 mm

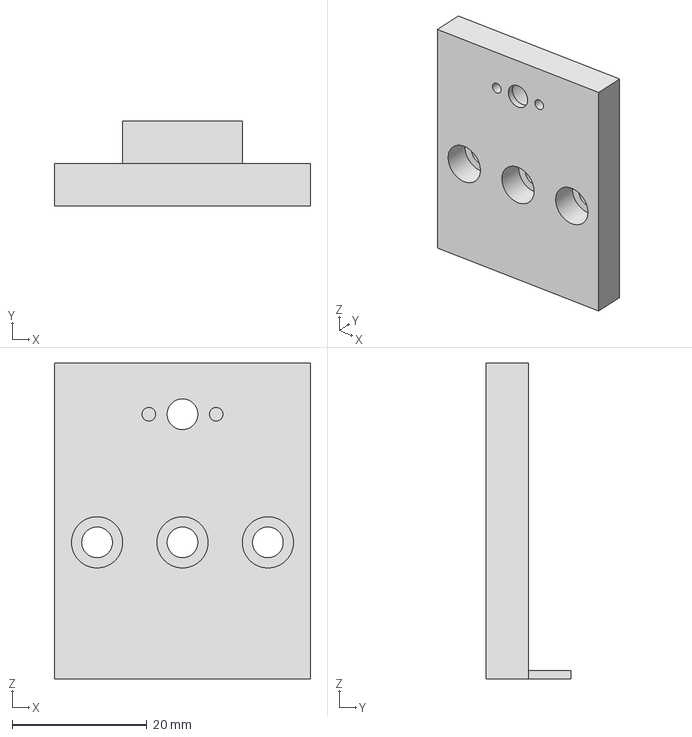
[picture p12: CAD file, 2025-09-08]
downloads/common/cad/BeamsplitterMounttoPolarisPinAdapterV3.stp
38.1 x 12.7 x 47.0 mm

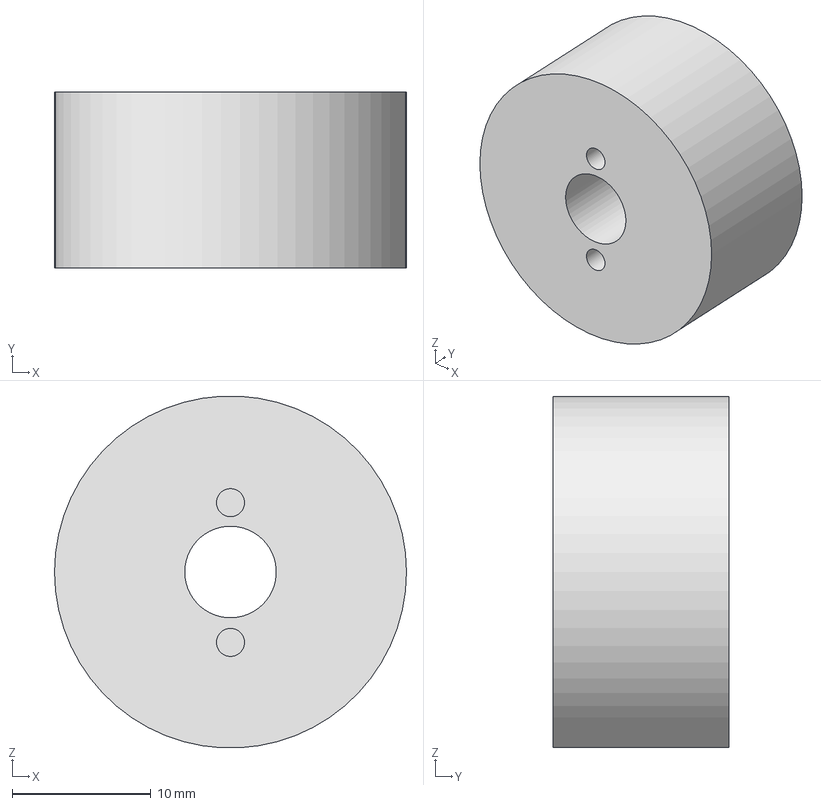
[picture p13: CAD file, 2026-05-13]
downloads/dvOPM/CAD/To Machine/PolarisPost_HeightAdjustment_0p5in_Machined.stp
25.4 x 12.7 x 25.4 mm

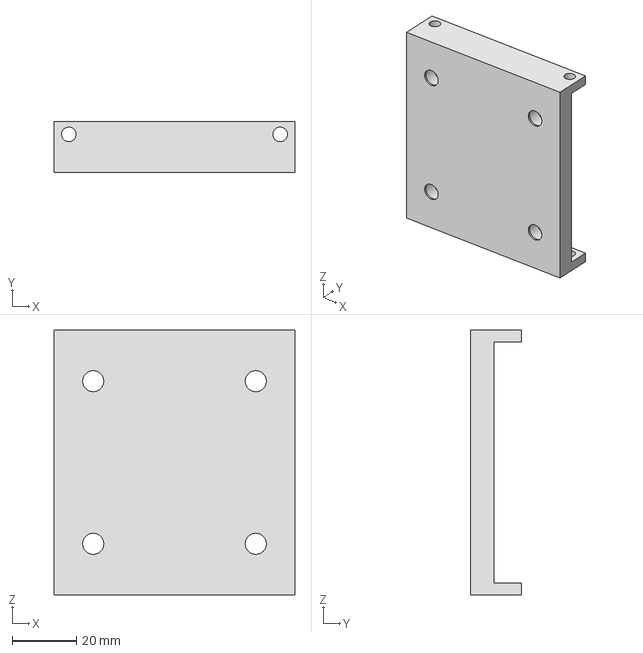
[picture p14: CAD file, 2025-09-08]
downloads/common/cad/Voicecoil_to_PY004_Coupler.stp
75.2 x 16.0 x 82.8 mm

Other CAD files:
downloads/common/cad/GalvoHoldertoPolarisMount.dwg
downloads/dvOPM/CAD/Assembly and Dependent Files/Baseplate Illum V3 L.dwg
downloads/dvOPM/CAD/Assembly and Dependent Files/Templates/English/ANSI (in).dwg
downloads/dvOPM/CAD/Assembly and Dependent Files/Templates/Metric/JIS.dwg
downloads/dvOPM/CAD/Assembly and Dependent Files/Templates/Standard.dwg
downloads/dvOPM/CAD/Assembly and Dependent Files/POLARIS-B1S-Step.step
downloads/dvOPM/CAD/Assembly and Dependent Files/Templates/Metric/GOST.dwg
downloads/dvOPM/CAD/Assembly and Dependent Files/POLARIS-MA45-Step.step
downloads/dvOPM/CAD/Assembly and Dependent Files/Templates/Metric/DIN.dwg
downloads/dvOPM/CAD/Assembly and Dependent Files/Baseplate as 1 V3.dwg
downloads/dvOPM/CAD/Assembly and Dependent Files/Templates/Metric/ISO.dwg
downloads/ASLM_CTASLM_Baseplate/CAD Assemblies/Cylindrical ASLM/AC254-030-A-Step.ipt
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

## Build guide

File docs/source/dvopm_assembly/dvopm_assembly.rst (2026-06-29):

.. _dvopmassembly-home:

######################################
DV-OPM Baseplate Assembly & Alignment
######################################

Detection Train Assembly
________________________

The detection assembly consists of a Mitakon Speedmaster 65 mm f/1.4 photographic lens serving as the primary objective (O1), followed by a filter wheel, a 90° folding mirror, a Nikon AF-S NIKKOR 85 mm f/1.4G lens serving as the secondary objective (O2), and a CMOS camera (Ximea MU196MR) for image acquisition. In contrast to conventional oblique plane microscopy (OPM) systems employing an objective lens and tube lens, this configuration relies solely on two coupled photographic lenses with careful alignment. Without tube lenses, the overall resolution of the system is limited by the pixel size of the detection camera; hence, the Ximea MU196MR was selected for its 1.4 µm pixel pitch. All optical elements were precisely calculated, pre-aligned, and mounted onto a custom baseplate, resulting in a mechanically constrained configuration that requires minimal alignment.

Due to the spatial and mechanical constraints of each optical element, as well as the non-telecentricity of the two photographic lenses, the relative spacing between them was predetermined and optimized using Zemax simulations to ensure optimal imaging performance.

The alignment procedure is centered around the filter wheel, which serves as the primary optical reference. Alignment begins with establishing a reference beam for the baseplate.

**Setting up the reference beam:**

1. Place the laser source on an elevated platform above the baseplate so that the beam propagates downward onto the baseplate.
2. Generate a collimated beam from the source using a collimator. A reflective collimator (Thorlabs RC08APC-P01) was used here to produce a beam diameter of 7.3 mm.
3. Direct the collimated beam downward using a 45° folding mirror. A 1" right-angle kinematic mount (Thorlabs KCB1) was used to reflect the beam downward toward the detection assembly.
4. Mount both the collimator and the folding mirror on translation stages to allow fine positioning of the beam.
5. Install two irises along the propagation path.
6. Place a flat mirror on the optical table at the beam incidence point to check for back-reflection.
7. Iteratively adjust the tip, tilt, and rotation of the 1" mirror to ensure the back-reflected beam passes through both irises.
8. Once complete, this establishes a straight and stable reference beam for downstream alignment.

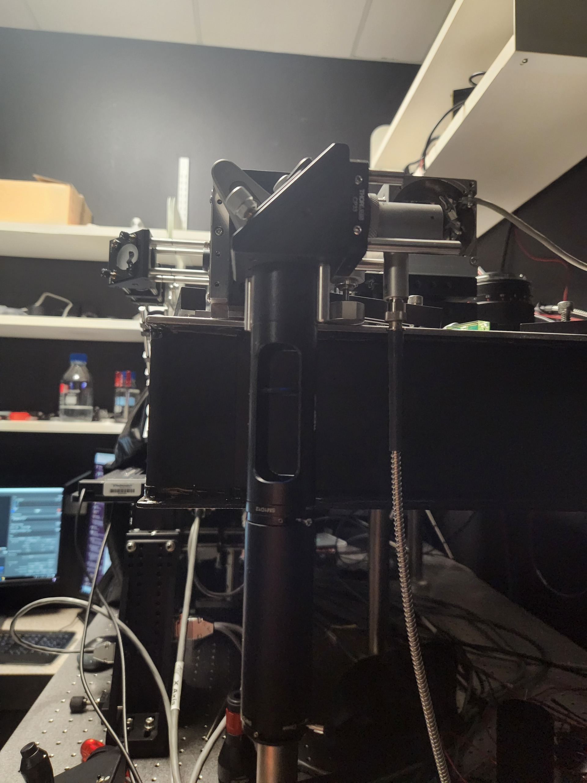
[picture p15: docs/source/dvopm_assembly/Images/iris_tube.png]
Reference beam with irises mounted on translation stages.


   **Figure 1:** Reference beam with irises mounted on translation stages.

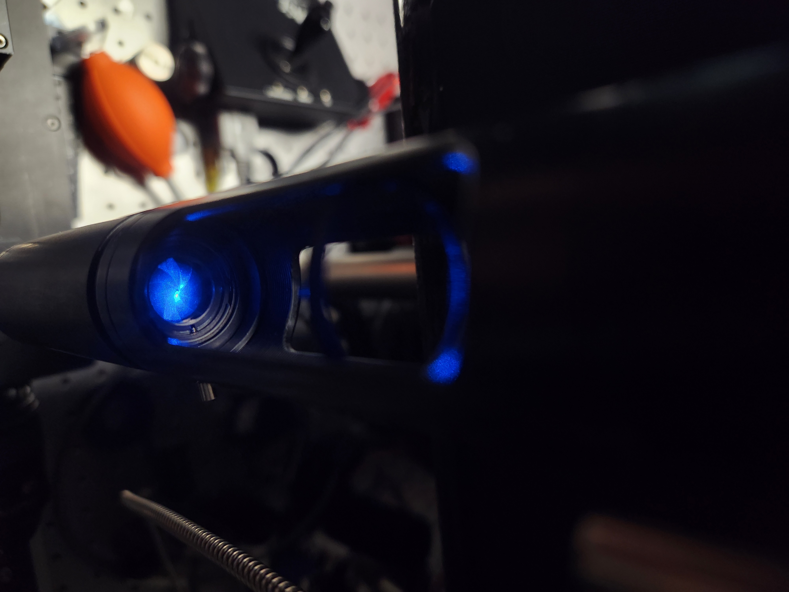
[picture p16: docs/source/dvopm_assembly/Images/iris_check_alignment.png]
Checking beam symmetry at the irises.


   **Figure 2:** Verify that the beam is centered on each iris aperture.

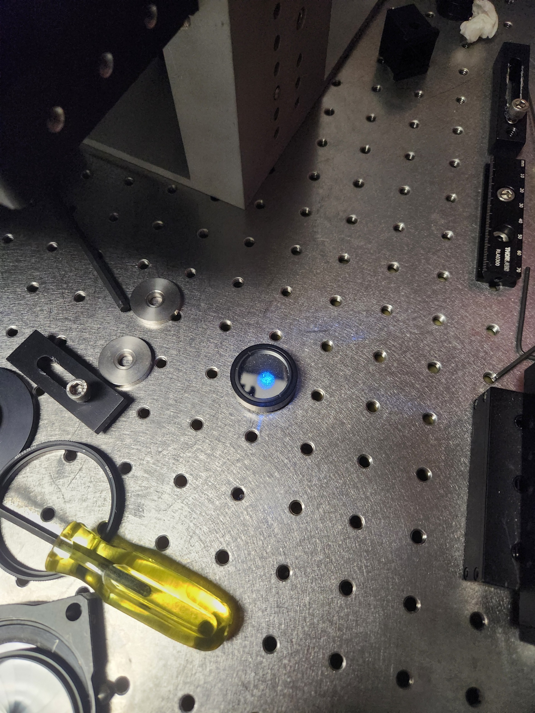
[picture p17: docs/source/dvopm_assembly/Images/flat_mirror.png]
Flat mirror installed for back-reflection alignment check.


   **Figure 3:** Installation of a flat mirror for back-reflection alignment verification.

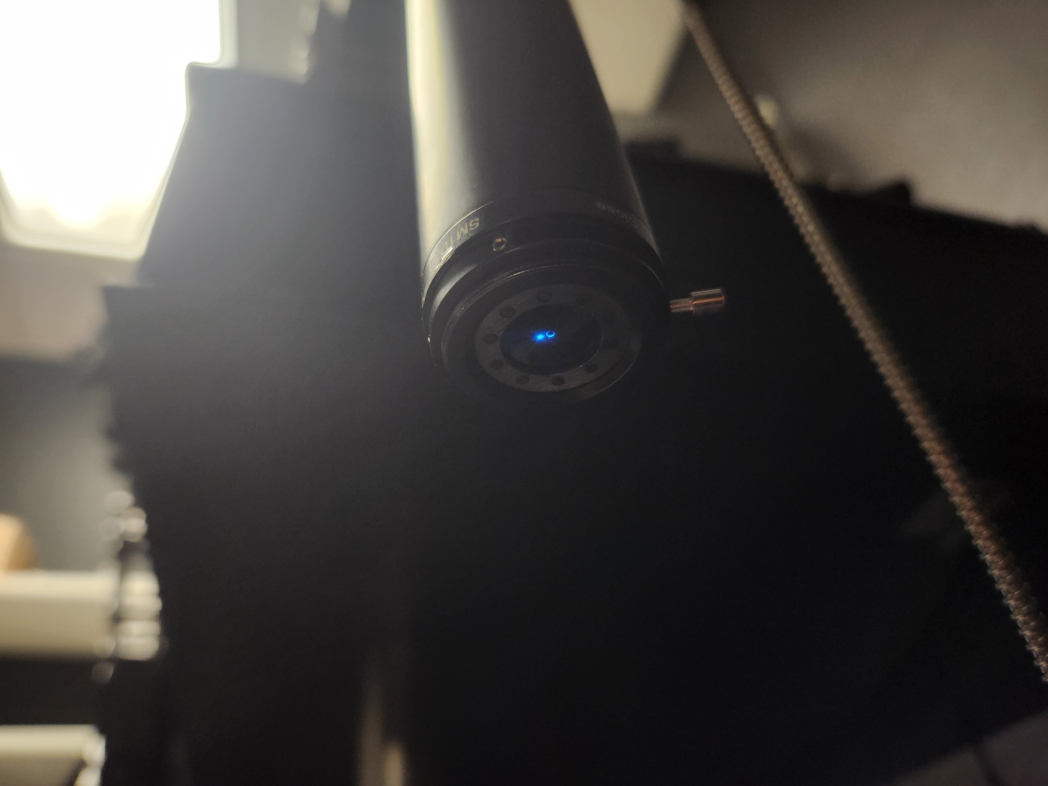
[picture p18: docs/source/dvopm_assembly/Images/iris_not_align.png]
Example of a misaligned reference beam.


   **Figure 4:** Example of a misaligned reference beam. The beam does not pass through the iris aperture.

The next step is to configure the photographic lenses. Because neither lens is telecentric, correct setup is critical for minimizing aberrations and achieving optimal performance.

O2 must be operated with its focus locked at infinity and its aperture fully open. Setting O2 to infinity focus immobilizes the internal focusing groups, fixing the effective focal length and the locations of the entrance and exit pupils.

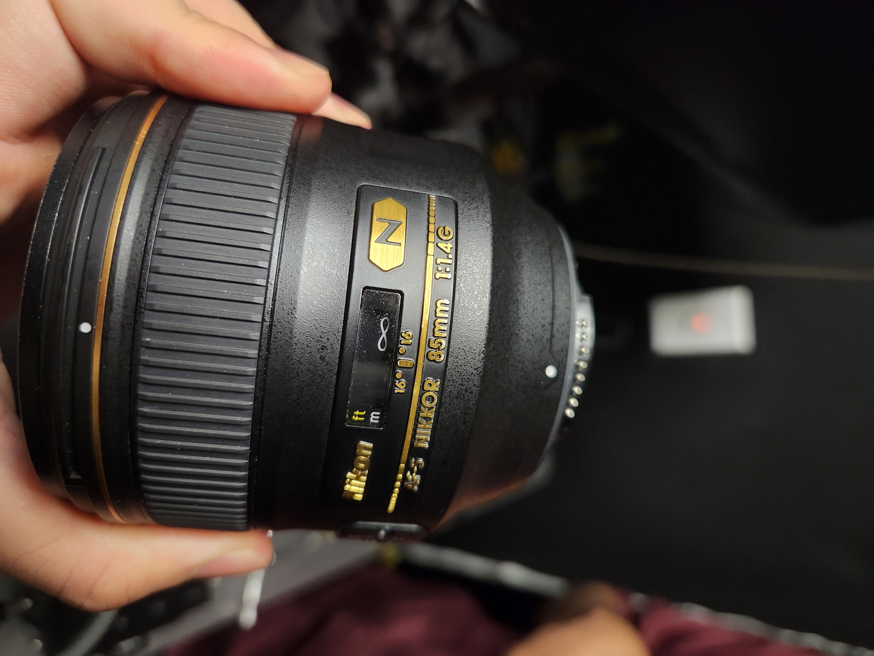
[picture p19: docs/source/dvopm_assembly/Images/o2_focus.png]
O2 focus ring locked to infinity.


   **Figure 5:** Lock the focus of O2 to infinity by rotating its focus adjustment ring.

Because the Nikon AF-S NIKKOR 85 mm f/1.4G does not include a mechanical aperture ring, the aperture must be opened manually. This can be accomplished by inserting a thin, rigid piece of material (e.g., hard cardboard) into the aperture control lever on the rear bayonet face of the lens. This fully opens the aperture and allows the lens to be stepped up to the camera.

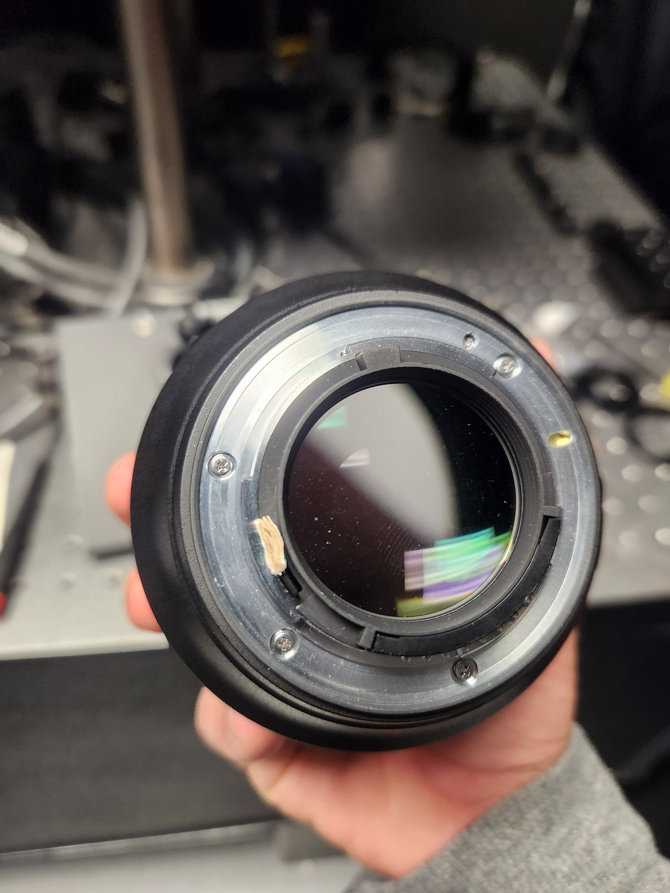
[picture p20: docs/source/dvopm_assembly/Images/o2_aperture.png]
O2 aperture opened with a cardboard shim.


   **Figure 6:** Open O2's aperture by inserting a cardboard shim into the aperture control lever on the rear of the lens.

The focus of O1 does not critically affect overall system performance and may be left at an arbitrary setting. However, O1 includes a mechanical aperture ring that allows the effective NA to be adjusted. The system can in principle be operated at full aperture (NA = 0.36). Due to the non-telecentric, non-corrected nature of the photographic lenses and the fact that the filter wheel aperture in the current configuration is smaller than the back pupil of O1, operating at full NA will introduce significant astigmatism without a corresponding improvement in resolution. It is therefore recommended to set O1 to a reduced aperture.

**Assembling the baseplate:**

1. Install a 2" mirror into a 2" kinematic mount (Thorlabs KCB2) and mount the filter wheel at its predetermined position on the custom baseplate.
2. Place a ground-glass diffuser or pinhole at the entrance aperture of the filter wheel.
3. Position the baseplate so that the reference beam passes straight through the pinhole. Light should be visible exiting the baseplate on the far side.
4. Install a mirror in a 4" lens tube and check for back-reflection while adjusting the tip and tilt of the kinematic mirror to establish a straight beam path for the exiting beam.

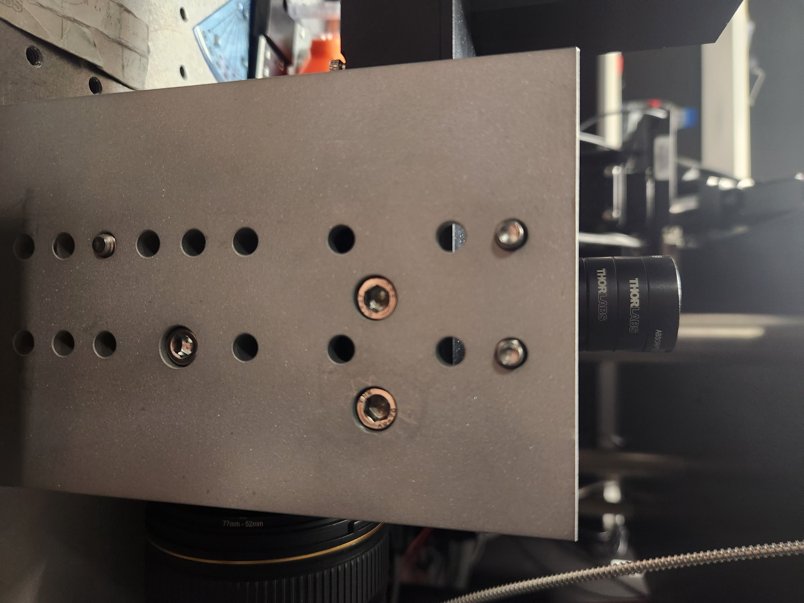
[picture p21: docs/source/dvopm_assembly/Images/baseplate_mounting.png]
Filter wheel and kinematic mirror mount installed on the baseplate.


   **Figure 7:** Filter wheel and kinematic mirror mount installed at their predetermined positions on the custom baseplate.

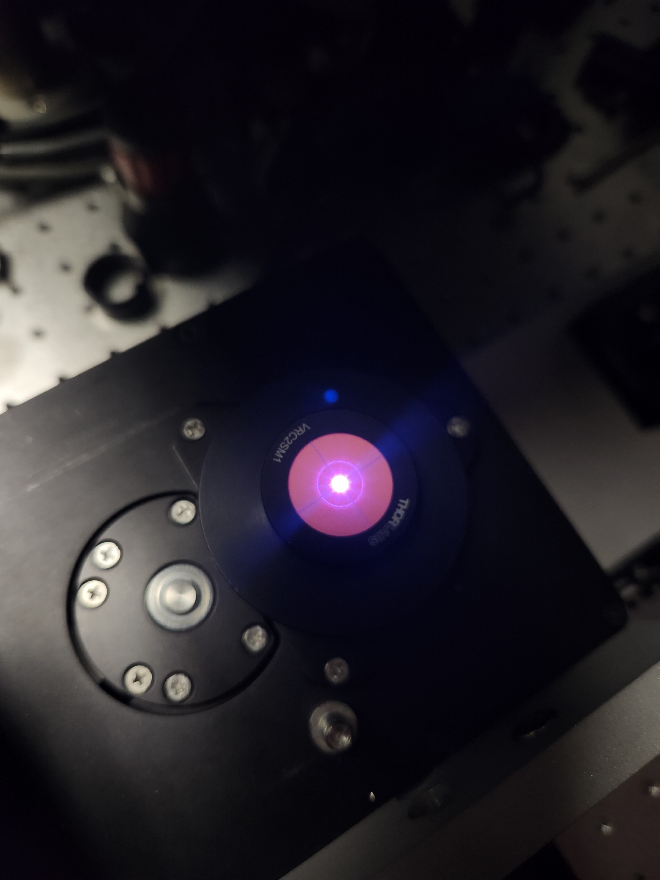
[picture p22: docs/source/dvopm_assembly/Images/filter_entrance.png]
Center alignment demonstrated by translating the reference beam through the filter wheel entrance.


   **Figure 8:** Center alignment demonstrated by translating the reference beam through the filter wheel entrance aperture.

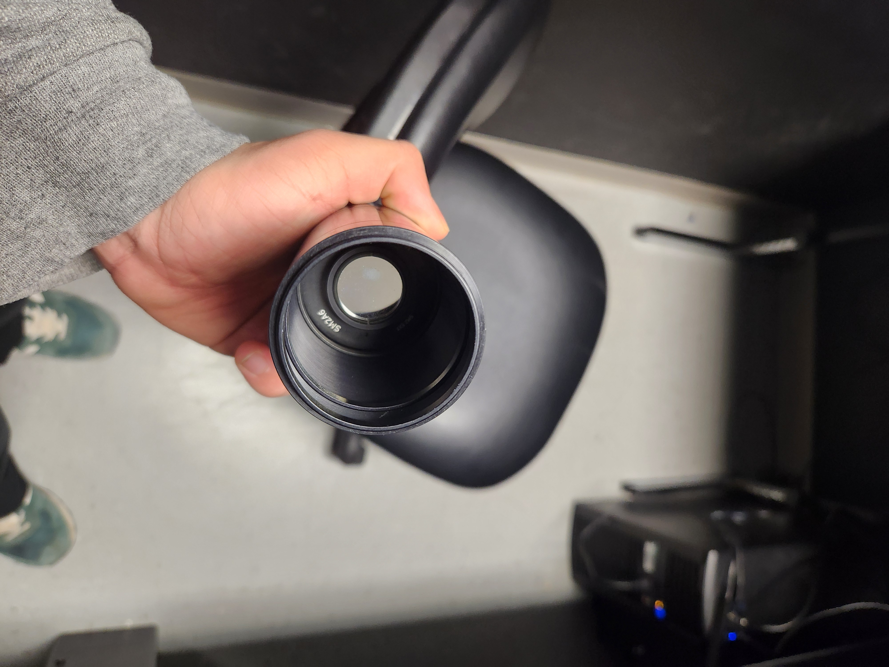
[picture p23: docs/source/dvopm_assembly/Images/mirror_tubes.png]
Mirror mounted on a lens tube for back-reflection alignment check.


   **Figure 9:** Mirror mounted on a lens tube used to verify alignment of the kinematic mount via back-reflection.

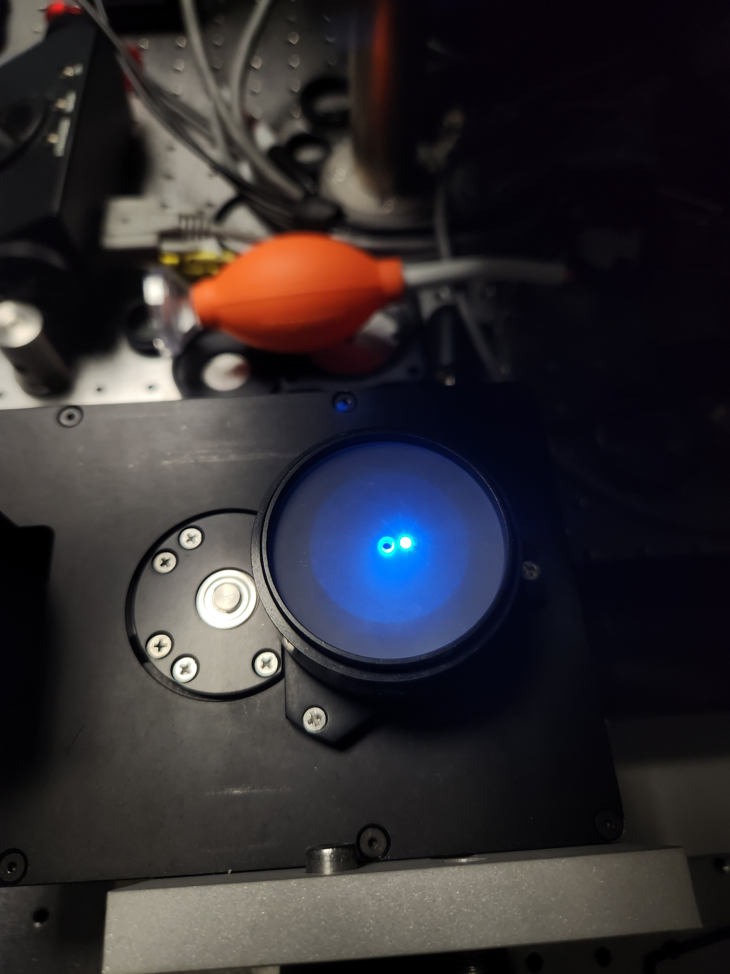
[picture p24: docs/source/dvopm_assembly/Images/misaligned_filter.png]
Example of a misaligned mirror mount showing off-axis back-reflection.


   **Figure 10:** Example of a misaligned beam: adjusting the tip and tilt of the kinematic mirror shifts the back-reflection off-axis.

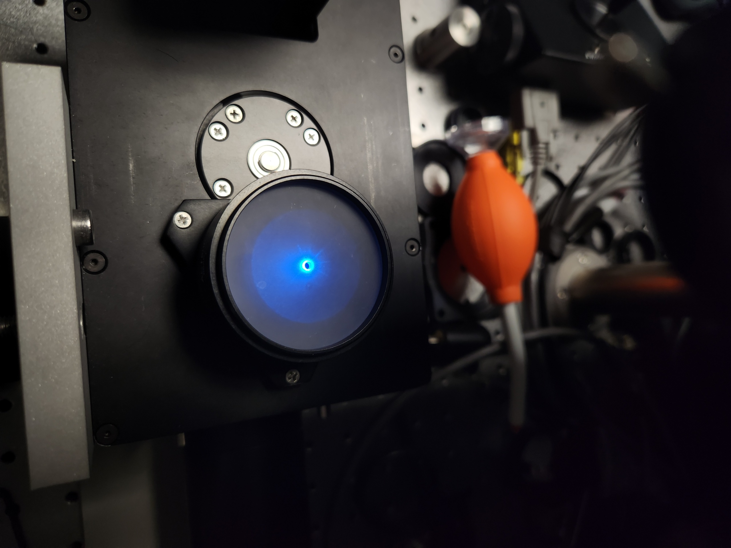
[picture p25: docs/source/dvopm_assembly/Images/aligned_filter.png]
Example of an aligned mirror mount with on-axis back-reflection.


   **Figure 11:** Example of an aligned beam: back-reflection is coaxial with the incident beam after tip/tilt correction of the kinematic mirror.

Once the beam path is established, install O2 in a reversed configuration and mount the camera to locate the optimal focus position. Rotate the camera to approximately 45° so that its entrance pupil is parallel to O2. Illuminate O2 with a large-diameter beam (ideally filling its back aperture) and translate the axial stage until a sharp focus is observed on the camera using its acquisition software. Insert neutral-density filters if necessary to avoid sensor saturation.

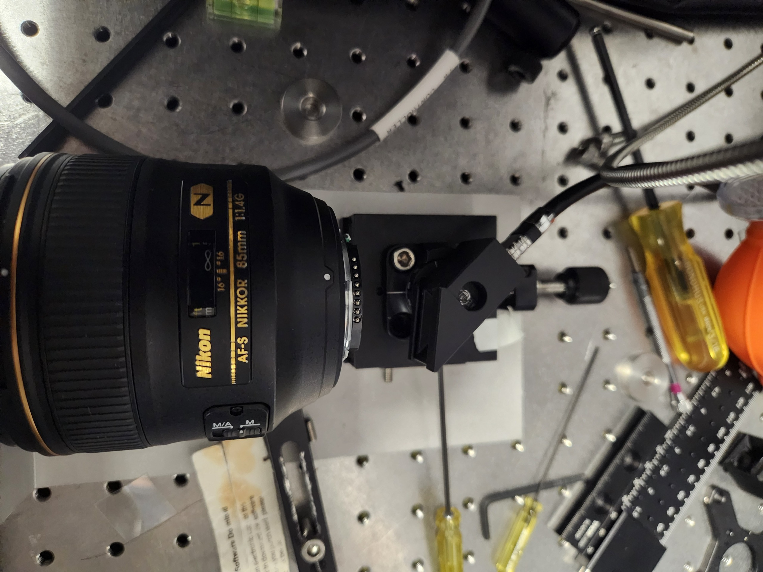
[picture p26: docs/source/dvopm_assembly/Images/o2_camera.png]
Setup for locating the optimal camera focus position relative to O2.


   **Figure 12:** Setup for locating the optimal focus position of the camera relative to O2.

---------------

Illumination Train Assembly
___________________________

Breakdown of Baseplate Holes
^^^^^^^^^^^^^^^^^^^^^^^^^^^^

The baseplate includes a series of holes for mounting the various optical components of the illumination train. Most of the optical components are mounted on Thorlabs Polaris Post with Polaris mounts, with a few exceptions. And there are some holes which purely for alignment purposes and would not be used once done with the alignment process. The following figure is a breakdown of the holes on the baseplate and their intended use:

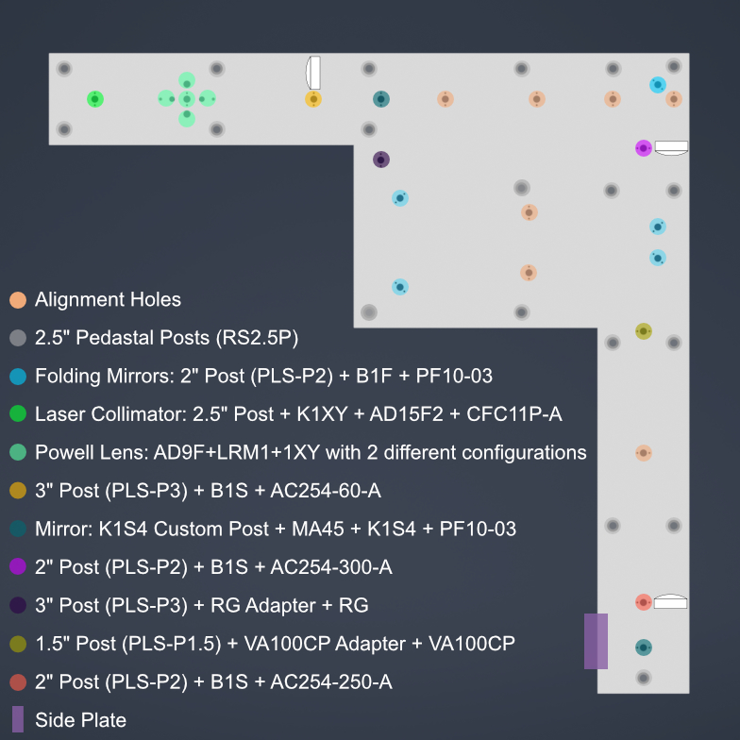
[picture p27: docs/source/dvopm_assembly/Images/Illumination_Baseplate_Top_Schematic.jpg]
A schematic of the baseplate labelled their intended use or optical components.


   **Figure 13:** Labelled schematic of the baseplate showing the intended use of each hole for mounting optical components or for alignment purposes.

Overview of the Illumination Train Assembly Process
^^^^^^^^^^^^^^^^^^^^^^^^^^^^^^^^^^^^^^^^^^^^^^^^^^^

The assembly of the illumination train is a multi-step process that involves the careful installation and alignment of various optical components. The following steps outline the general procedure for assembling the illumination train:

1. Mount the baseplate on the pedastal posts

2. Laster Collimation and Alignment

3. Mounting the Galvo Scanner and the first K1S4 mount with mirror 

4. Mounting the foldings Mirrors and ensuring alignment

5. Mounting the Optical Lenses

6. Mount the second K1S4 mount with mirror to fold the beam up

7. Gluing the D-Shaped Mirror on the Side Plate

8. Fastening the Side Plate on the main Baseplate.

9. Mounting the Powell Lens

10. Mounting Mechanical Slit

10.Cross-check the positon of the Powell and use the translation stage to fine-tune the position of the Powell lens.

---------------

Mounting Baseplate on Optical Table
^^^^^^^^^^^^^^^^^^^^^^^^^^^^^^^^^^^

To mount the baseplate onto an optical table, the process requires screwing 1/4"-20 screws onto 2.5" pedastal posts (`RS2.5P <https://www.thorlabs.com/item/RS2.5P>`_). There are multiple holes on the baseplate for pedastal posts, we recommend at least using the 5 pedastal posts for all 5 vertices. You could either use clamps to fasten the pedastal posts on the optical table or use cap screws in which case first fasten the pedastal posts on the optical table and then mount the baseplate on top of the pedastal posts. 
The whole system has been made keeping in mind of the height of the pedastal posts, so using 2.5" pedastal posts will ensure that the baseplate is at the proper height to correctly couple with the detection module.

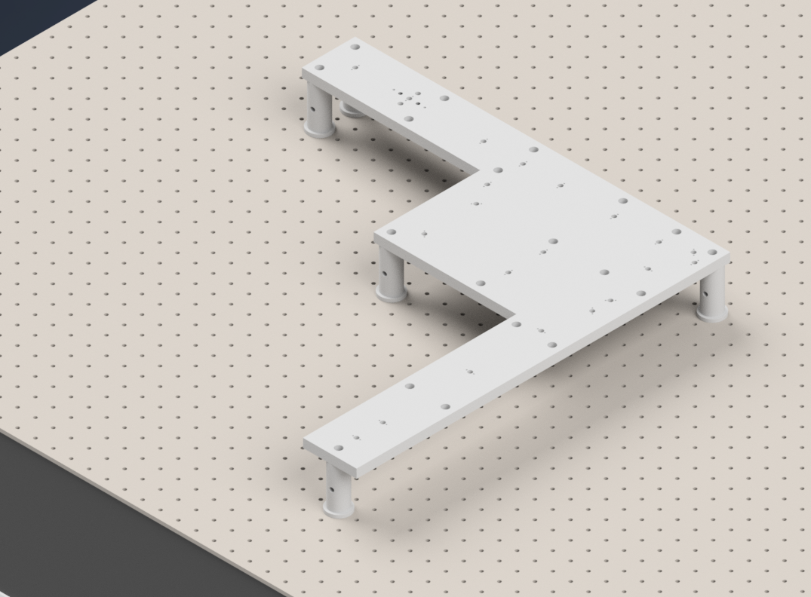
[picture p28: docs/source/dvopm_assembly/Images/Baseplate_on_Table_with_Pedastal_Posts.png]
Mounting the baseplate on the optical table using pedastal posts.


    **Figure 14:** Mounting the baseplate on the optical table using pedastal posts.

---------------

Initial Laser Collimation
^^^^^^^^^^^^^^^^^^^^^^^^^

When first assembling the system, ensuring proper output collimation from the fiber laser source is critical. There are multiple checks that one can take for this step, but we utilize a combination of a `shear-plate interferometer <https://www.thorlabs.com/newgrouppage9.cfm?objectgroup_id=2970>`_ and two pinhole apertures placed at opposite ends along the length of the baseplate. Shear-plate interferometers are designed to split and interfere an input beam of coherent light, such that when the beam is collimated there are interference fringes aligned vertically with a reference line. The fiber laser collimator we used for this system is the `Thorlabs CFC11A-A <https://www.thorlabs.com/thorproduct.cfm?partnumber=CFC11A-A>`_, which features an adjustable barrel which controls the position of collimation optics within the element.

The basic assembly process involves first inserting and fixing the CFC11A-A into a Thorlabs AD15S2 adapter, which allows it to then be mounted into a 2.5" Polaris K1XY mount (We used a combination of a custom machined 0.5" spacer with 2" Polaris Post). This assembly is then mounted onto the respective Polaris post at the start of the baseplate. The fiber laser source is then able to be directly mounted into the CFC11A-A, making sure that the protrusion on the fiber wire aligns with the open section of the CFC11A-A port. The basic process of ensuring collimation then involves turning on the laser source, and placing the shear-plate interferometer such that the input port aligns with the output of the laser unit. Then, by slowly adjusting the barrel of the CFC11A-A and observing the interference fringe orientations along the top display of the interferometer, one is able to adjust the beam until it is properly collimated.

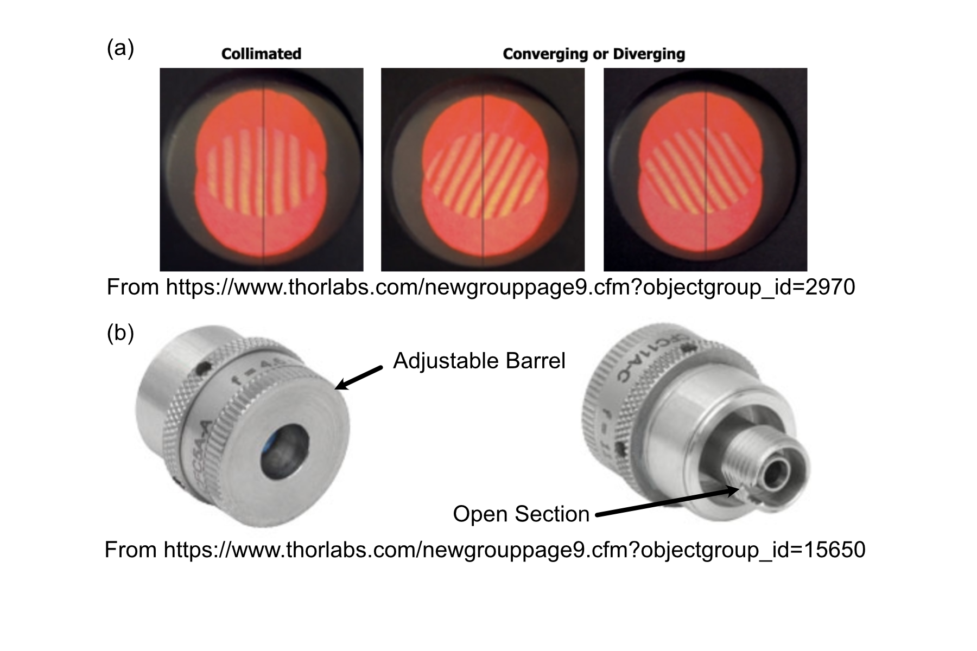
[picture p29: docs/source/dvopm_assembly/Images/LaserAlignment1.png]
Shear Plate interferometer and collimator lens


    **Figure 15:** Shear Plate interferometer and collimator lens

----------------

Initial Alignment
^^^^^^^^^^^^^^^^^

With the beam collimated, the process of beam alignment involves adjusting the position control knobs on the K1XY to have the beam pass through two pinhole apertures along the optical path. The height of the initial laser output is designed to be at 3.75" above the top surface of the baseplate, so selecting appropriate post heights for the apertures such that their centers rest at 3.75" is essential. 
In our case we use a 2.5" post with 1XY mount to hold the `P2000K1 pinhole apertures <https://www.thorlabs.com/thorproduct.cfm?partnumber=P2000K1>`_ or any adjustable iris which has SM1 threading, however  if using Polaris 1XY mount, **the user must not adjust the XY adjusment screws on the 1XY mount and treat it as fixed in the whole alignmennt process**.
The other way is using `Thorlabs ID12 <https://www.thorlabs.com/thorproduct.cfm?partnumber=ID12>`_ pinhole apertures, so using a post height of 3.25" will ensure that they are at the proper height for alignment. We designed a `custom ID12 to Polaris adapter <https://github.com/TheDeanLab/altair/tree/main/downloads/common/cad>`_ to ensure the aperture is at the proper height and properly aligned along the designated Polaris axis. 
Either way, the key is to ensure that the pinholes are at the correct height and you could have one of these pinholes placed at the powell lens hole and one at the other end of the baseplate as shown in the figure below. There are multiple alignments holes in between and one can use them too, it is always better to check far away. 
With the pinholes placed, the process becomes iterative by making small adjustments on the K1XY tip/tilt knobs and XY position screws until the beam passes through both pinholes.

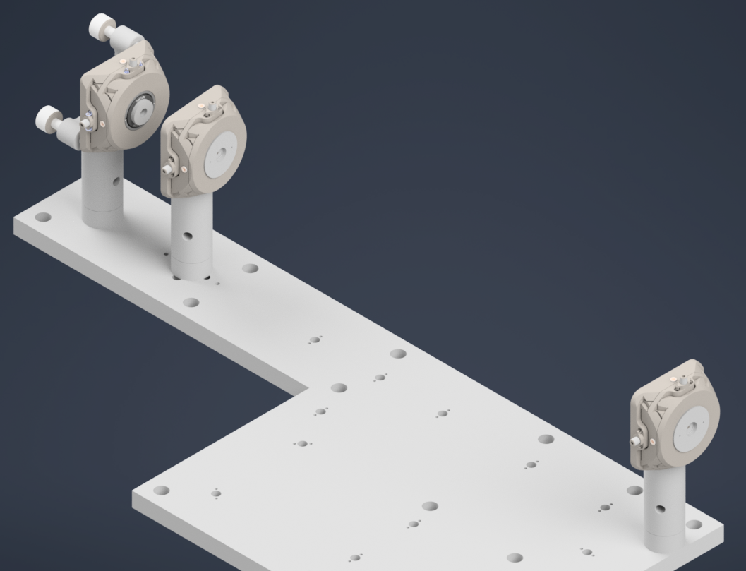
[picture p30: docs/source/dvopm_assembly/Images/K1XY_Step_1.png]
Initial beam alignment using pinholes


    **Figure 16:** Alignment setup with a pair of pinholes with 1XY mount for initial beam alignment.

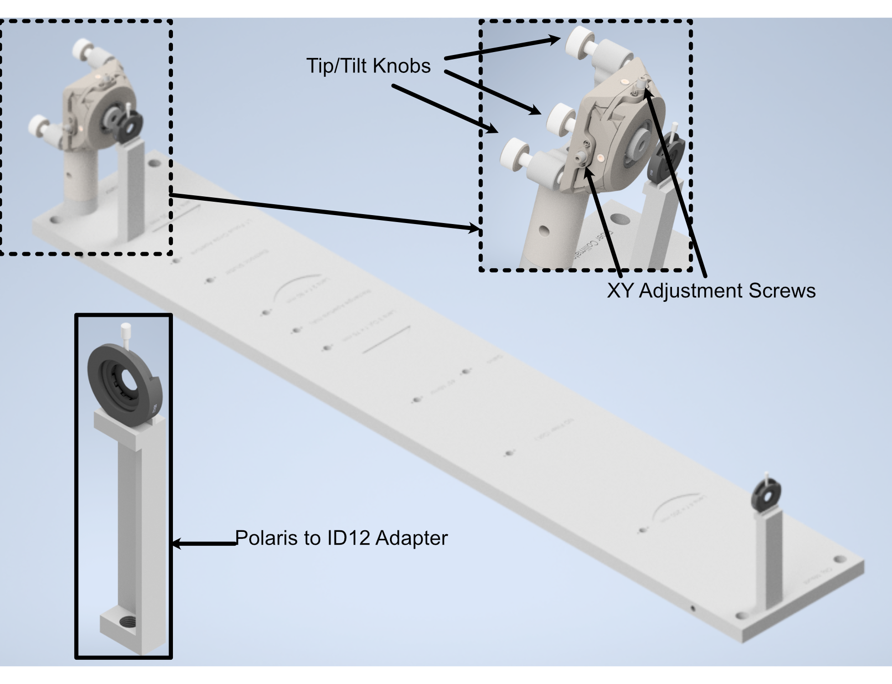
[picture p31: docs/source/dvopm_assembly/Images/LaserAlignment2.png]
Performing beam alignment across the baseplate


    **Figure 17:** Performing beam alignment using ID12 and custom adapter for it.

---------------

Placing the Galvo and the K1S4 Mirror Mount
^^^^^^^^^^^^^^^^^^^^^^^^^^^^^^^^^^^^^^^^^^^

Now that the beam is collimated and aligned, the next step is to mount the galvo scanner and the first K1S4 mount with mirror, which will decrease the optical axis height by a inch. 
For the Resonant Galvanometer, use a 3" Polaris Post, and mount the custom galvo adapter on top of the post using dowell pins and 3/8" screw, then carefully insert the galvo scanner through the adapter bore and fasten a little using 3/8" screws but do not tighten yet. Make sure the reflecting surface faces the correct direction.
For the K1S4 mount, use a custom K1S4 post and mount the K1S4 on top of the post using dowell pins, then insert a mirror into the mount and fasten it using the provided screw. 
Now we also put in the first folding mirror which is at the corner of the baseplate, and this mirror is mounted in a B1F mount which gets mounted on the 2" Polaris Post. Detailed instructions for mounting the optics in B1F can be accessed in ThorLabs Specs Sheet.
We need to have atleast 2 pinholes for this step, one nearest to the K1S4 mount and one at the end of the baseplate. We need to use 1.5" post with 1XY mount to hold the pinhole.
The figure below shows the galvo scanner, the first K1S4 mount with mirror, the first folding mirror mounted on the baseplate and a pinhole at the end of the baseplate.
Now the goal is to make sure that the beam reflects off the mirror and passes through the pinhole at the end of the baseplate and at this point. For the vertical alignment, you can adjust the tip knob on the K1S4 mount and the rotation of the galvo scanner. Adjust the galvo scanner to make sure the beam the passthrough the first pinhole and adjust the tip knob of the K1S4 mount to make sure the beam passes through the second pinhole at the end of the baseplate. Iteratively adjusting both will make the beam at the correct height throughout, if beam is laterally shifted on the pinholes, use the tilt knob on the K1S4 mount to make the adjustment.
Once the beam is passing through the pinhole at the end of the baseplate, you can then tighten the screws on the galvo scanner.

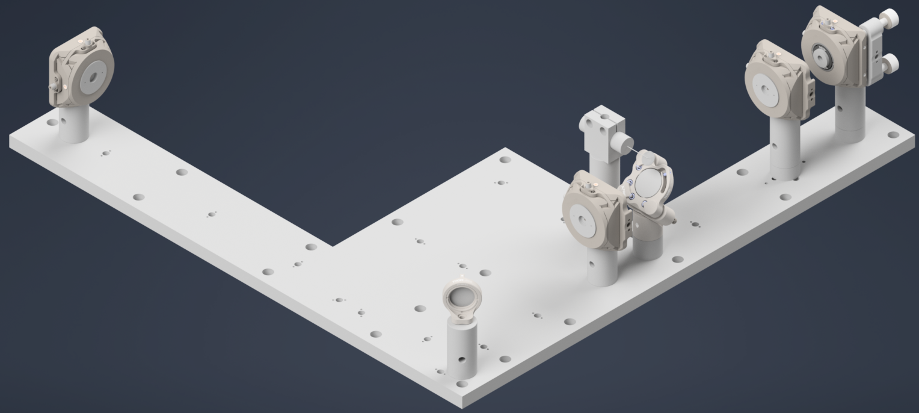
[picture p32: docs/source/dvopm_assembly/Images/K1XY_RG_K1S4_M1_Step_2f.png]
Aligning the galvo scanner and the first K1S4 mount with mirror


    **Figure 18:** Aligning the beam across the baseplate through the galvo scanner and the first K1S4 mount and the first folding mirror

---------------

Folding Mirrors
^^^^^^^^^^^^^^^

Now, the next step is to mount the remaining folding mirrors and ensure that the beam still passes through the pinholes. We begin by only the corner mirror first.
Ideally, you wouldn't need to make any adjustment to make the beam pass through the pinholes, if the beam aligned correctly in the previous step and that the folding mirrors are correctly mounted. 
If there is still slight misalignment, you can first try to rotate the folding mirrors' post (they have a little room play with) if not you can adjust the tip/tilt knobs on the K1S4 mount until the reflected beam passes through both pinholes.
Also, you could use the aligment holes in between the folding mirrors at different positions to inspect at which point is the beam getting misaligned if any, and make the adjustment accordingly.

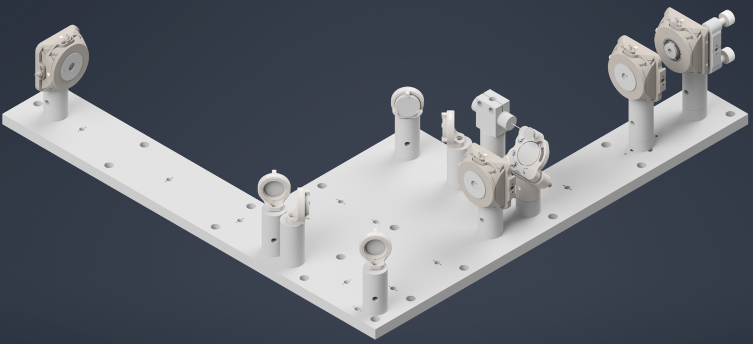
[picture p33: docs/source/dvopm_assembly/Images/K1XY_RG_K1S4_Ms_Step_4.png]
Aligning the folding mirror


    **Figure 19:** Mounting all the folding mirrors in the path and ensuring the beam is properly aligned through the pinholes.

---------------

Mounting the Optical Lenses
^^^^^^^^^^^^^^^^^^^^^^^^^^^

Now that the beam is properly aligned with the folding mirrors, the next step is to mount the optical lenses. 
We only mount the achromatic doublet lenses first, and the powell lens is mounted at the end.

The f=60mm AC254-60-A achromatic doublet lens is mounted on a 3" polaris post in a B1S mount, and the f=300mm AC254-300-A achromatic doublet lens is mounted on a 2" polaris post in a B1S mount and the f=250mm AC254-250-A achromatic doublet lens is mounted on a 2" polaris post in a B1S mount as well.
The process of mounting the lenses is straightforward, but the key is to ensure that the lenses are mounted at the correct positions, facing the correct direction, and that the beam passes through the center of the lenses. The figure below shows the achromatic doublet lenses mounted on the baseplate.
You could chose to check the back reflection of the lenses to make sure they are properly mounted and that the beam is passing through the center of the lenses, but it is not necessary.

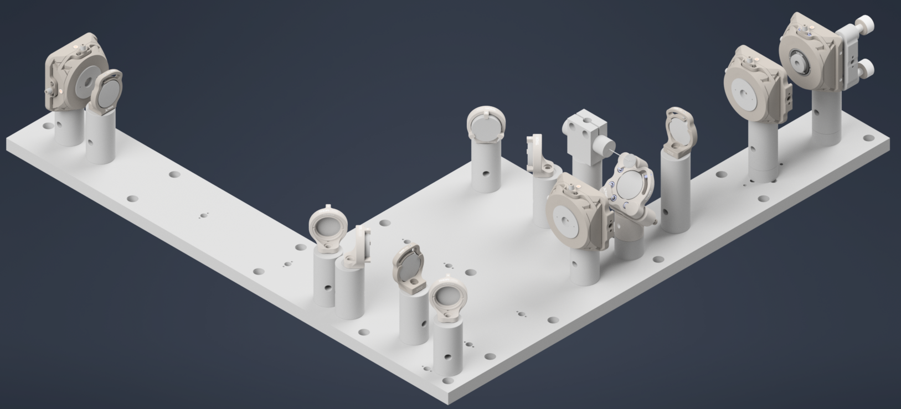
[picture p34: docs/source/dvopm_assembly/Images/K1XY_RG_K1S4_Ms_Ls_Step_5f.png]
Mounting the achromatic doublet lenses on the baseplate


    **Figure 20:** Mounting the achromatic doublet lenses on the baseplate

---------------

Fold the Beam Up
^^^^^^^^^^^^^^^^

Now, switch the 1XY mount with pinhole at the end of the baseplate with the second K1S4 mount with a mirror which will fold the beam up.

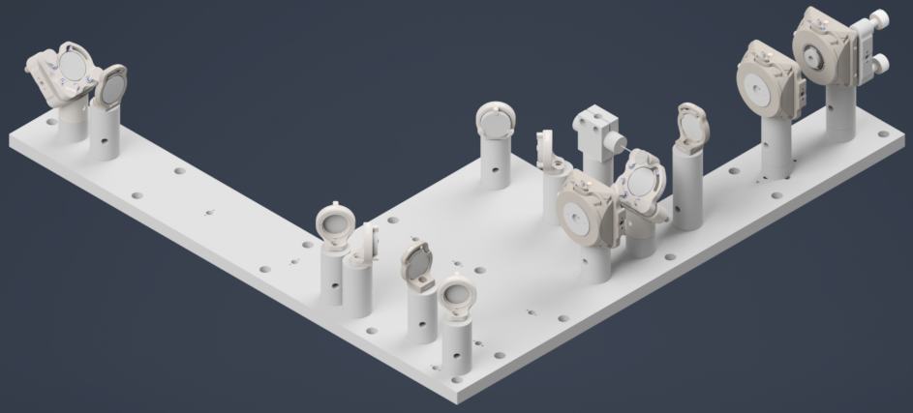
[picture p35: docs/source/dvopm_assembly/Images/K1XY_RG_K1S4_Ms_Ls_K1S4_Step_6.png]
Mounting the second K1S4 mount with mirror


    **Figure 21:** Mounting the second K1S4 mount with mirror

Now, the final alignment check is to make sure the beam is correctly folding  up and passing through the center.
For this step, we used a `DG10-1500-H1-MD <https://www.thorlabs.com/thorproduct.cfm?partnumber=DG10-1500-H1-MD>`_ put on a custom adapter. The custom adapter can be mounted to the side of the baseplate and you can just place the Alignment disk on top of the adapter.

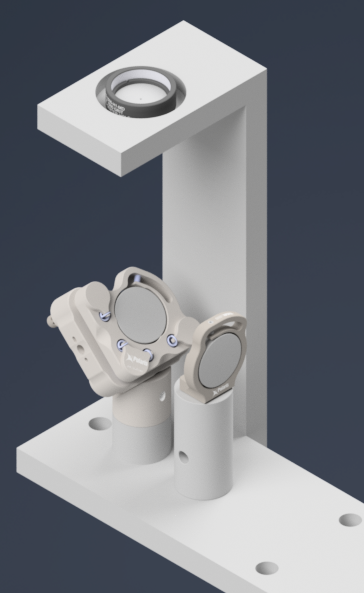
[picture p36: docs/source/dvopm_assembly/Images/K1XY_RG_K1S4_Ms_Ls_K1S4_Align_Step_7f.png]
Alignment disk mounted on the side of the baseplate for final alignment check.


    **Figure 22:** Alignment disk mounted on the side of the baseplate for final alignment check.

---------------

Gluing the D-Shaped Mirror on the Side Plate
^^^^^^^^^^^^^^^^^^^^^^^^^^^^^^^^^^^^^^^^^^^^

Now, we need to glue the D-Shaped mirror on the side plate and then fasten the side plate on the main baseplate. The D-shaped mirror is used to reflect the beam from the illumination train into the detection module, so it is crucial to ensure that it is properly aligned and securely attached.
The D-shaped mirror is glued onto the side plate using a high-quality optical adhesive. We used `Norland Optical Adhesive 81 <https://www.thorlabs.com/thorproduct.cfm?partnumber=NOA81>`_, which is a UV-curable adhesive that provides strong bonding and excellent optical clarity. 
The process involves applying a small amount of the adhesive to the socket in the side plate where the D-shaped mirror will be placed. You don't a thick layer of adhesive, just a thin layer evenly applied to the base and curved surface. Then place the D-Shaped mirror followed by curing from all the directions, and then curing it under UV light according to the manufacturer's instructions.

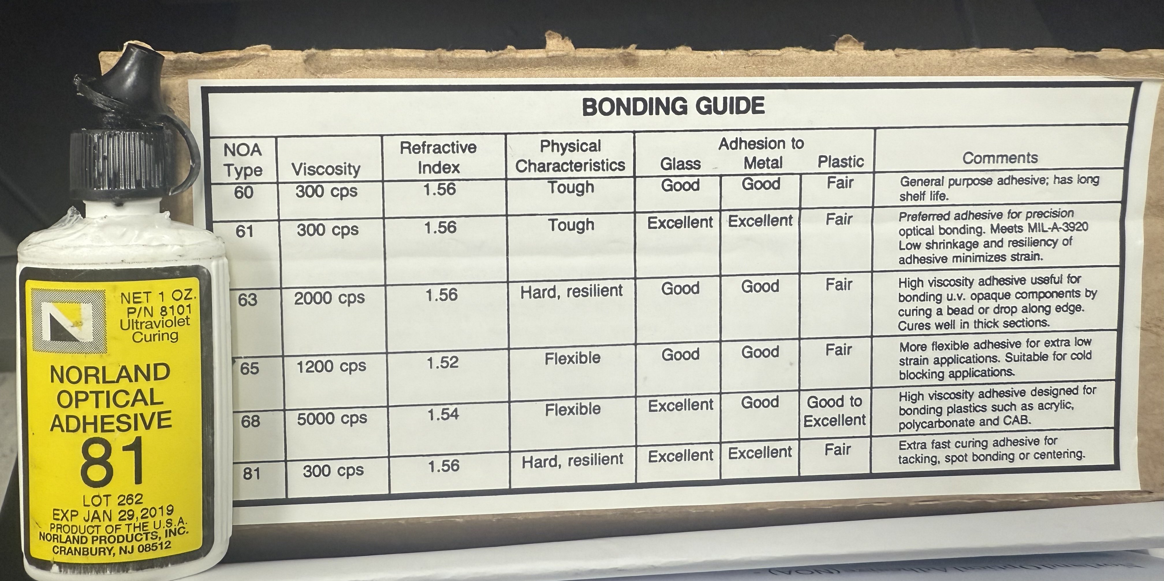
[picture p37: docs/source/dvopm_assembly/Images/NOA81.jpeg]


    **Figure 23:** The choice of glue used for attaching the D-Shaped mirror.

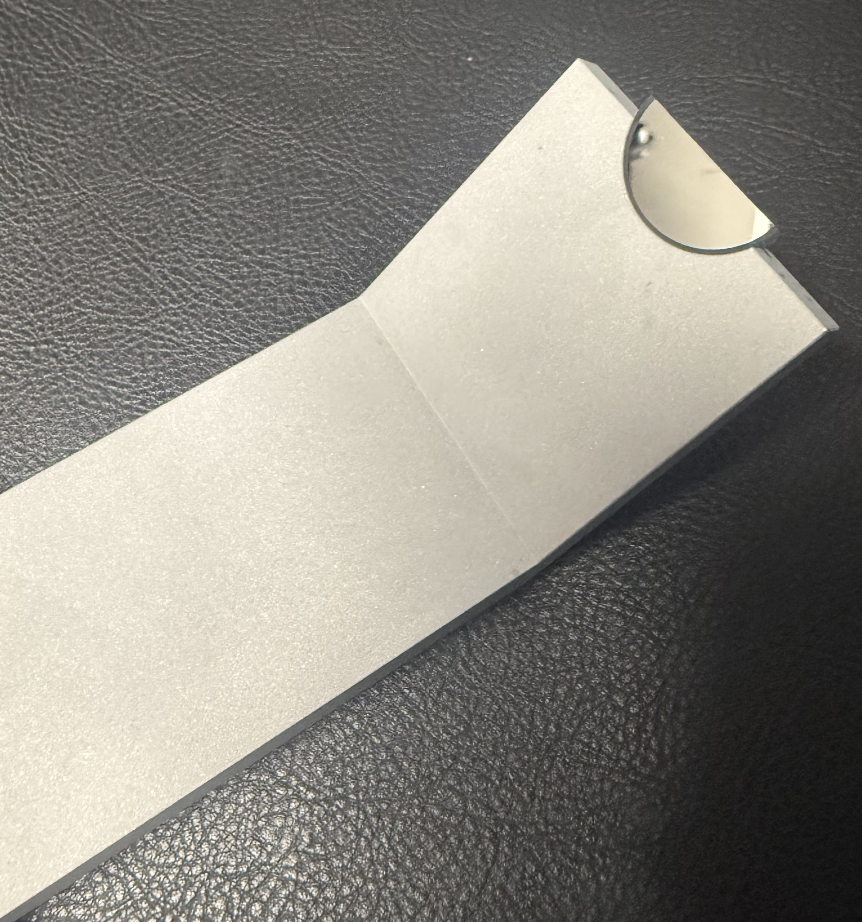
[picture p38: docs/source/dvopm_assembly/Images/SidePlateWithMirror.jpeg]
D-Shaped mirror glued onto the side plate.


    **Figure 24:** D-Shaped mirror glued onto the side plate.

---------------

Mounting the Side Plate 
^^^^^^^^^^^^^^^^^^^^^^^

Once the D-shaped mirror is securely attached to the side plate, the next step is to fasten the side plate onto the main baseplate. The side plate is designed to be mounted onto the main baseplate using dowell pins and 1/4-20 screws, so you will need to put the dowell pins in the baseplate side holes and then align the holes on the side plate on the main baseplate and then secure it in place using screws.

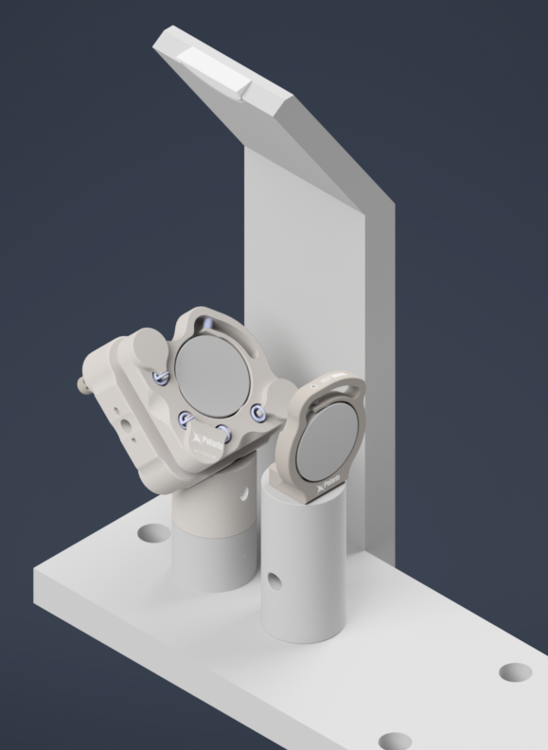
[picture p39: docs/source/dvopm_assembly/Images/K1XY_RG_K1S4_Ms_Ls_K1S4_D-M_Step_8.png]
Side plate fastened onto the main baseplate.


    **Figure 25:** Side plate fastened onto the main baseplate.

-------------------------

Powell Lens Assembly
^^^^^^^^^^^^^^^^^^^^

Our illumination path utilize a Powell lens as the element that forms the light sheet profile. Our mounting scheme for the Powell lens offers control over all 3 axes (x, y,
and z), where the Polaris 1XY Mount covers x and y and the LNR25M covers z. We found that outside of the Polaris 1XY
for centering the Powell lens precisely on the beam, due to tolerances of the Powell lens from Laserline, we
also needed to adjust the distance between the Powell lens and L2 to have our physical system align with our
simulations.

**Step 1: Fixing the Powell lens into the AD9F Mount**

For the first step, get a piece of optical tissue paper and the AD9F and Powell lens. Place the flat face of the
Powell lens onto the tissue paper, and then place the AD9F onto the Powell lens such that the front surface of the
smaller side of the AD9F is flush with the flat face of the Powell lens. Use the two mounting screws on the AD9F to
secure the lens in place.

.. card:: Powell Lens into AD9F Assembly

   .. raw:: html

      <video controls style="width:50%;">
        <source src="Images/Videos/Assembly/PowellAD9F.mp4" type="video/mp4">
        your browser doesn't support video
      </video>

**Step 2: Install the LRM1 rotation Mount into the Polaris 1XY**

Screw the threaded portion of the LRM1 into the threaded hole on the Polaris 1XY until the back surface of the LRM1
is flush with the front of the 1XY.

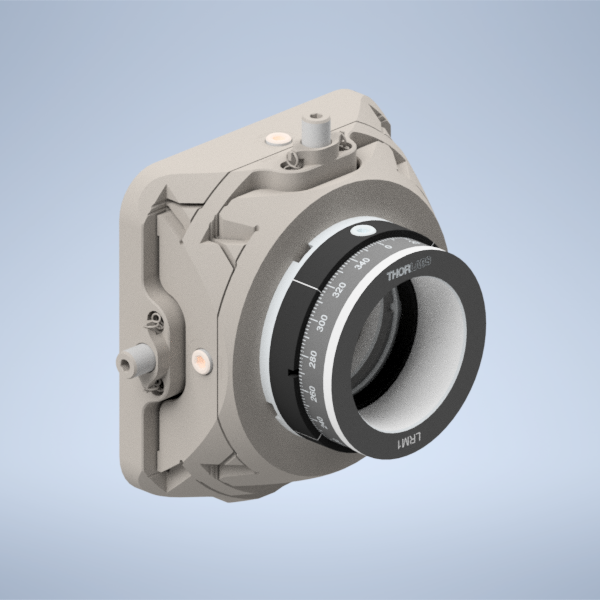
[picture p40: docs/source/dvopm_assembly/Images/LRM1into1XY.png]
Screwing the LRM1 into the 1XY


    **Figure 26:** Screwing the LRM1 into the 1XY

**Step 3: Install the LNR25M onto the Baseplate**

There are a variety of holes on the baseplate that one can use to fix the LNR25M in place. In the graphic below, the
two holes in red on the top of the LNR25M allow you to thread 1/4-20 screws directly through the LNR25M into the
threaded holes on the baseplate below. There are also two 3 mm-diameter dowel pins on the bottom of the LNR25M that
have corresponding holes on the baseplate in blue. Finally, there are three holes on the baseplate in yellow that
correspond to threaded holes on the bottom of the LNR25M, 1/4-20 screws can be used to secure the LNR25M through
these holes the same way that one would fix the other Polaris posts on the baseplate in place.

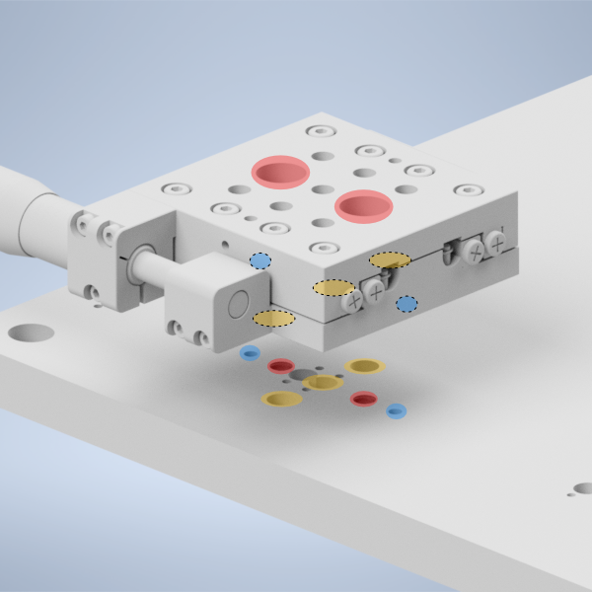
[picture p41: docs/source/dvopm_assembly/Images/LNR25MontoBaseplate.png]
placing the LNR25M onto the baseplate


    **Figure 27:** placing the LNR25M onto the baseplate

**Step 4: Fix the 1" Polaris Post onto the LNR25M to Polaris adapter**

Then take the LNR25M to Polaris adapter and using the same 2 mm dowel pins and 1/4-20 screws that the other Polaris
posts in the system use, fix the 1" Polaris post onto the adapter by screwing in a 1/4-20 screw from the bottom of
the adapter into the post.

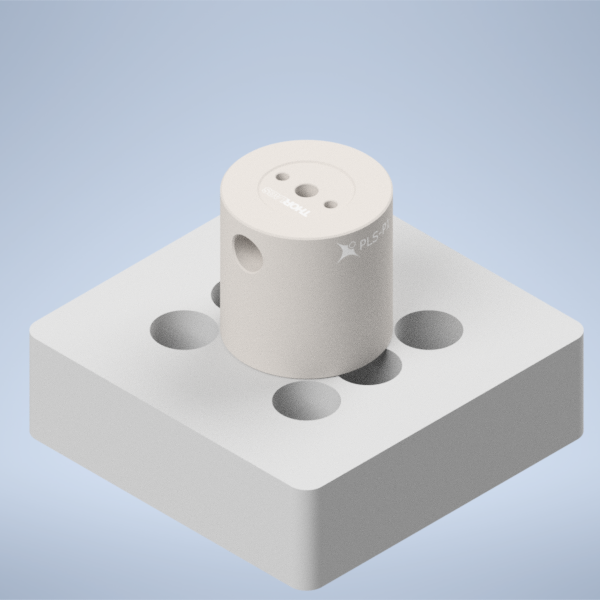
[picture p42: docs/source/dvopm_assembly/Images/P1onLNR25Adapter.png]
placing the 1" Polaris Post onto the LNR25M Adapter


    **Figure 28:** placing the 1" Polaris Post onto the LNR25M Adapter

**Step 5: Install the LNR25M to Polaris adapter onto the LNR25M**

Then using the four holes on the top of the adapter surrounding the 1" post, place 1/4-20 screws in those holes and
screw them into the top of the LNR25M

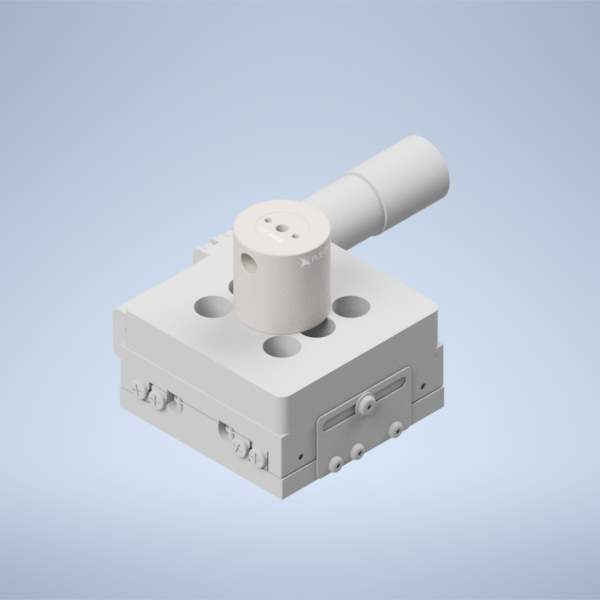
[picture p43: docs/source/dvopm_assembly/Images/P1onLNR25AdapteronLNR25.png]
placing the LNR25M Adapter onto the LNR25


    **Figure 29:** placing the LNR25M Adapter onto the LNR25

**Step 6: Fix the Polaris 1XY onto the 1" Polaris post**

Using an 8-32 screw and the 2 mm dowel pins, fix the Polaris 1XY onto the top of the 1" Polaris post assembly.

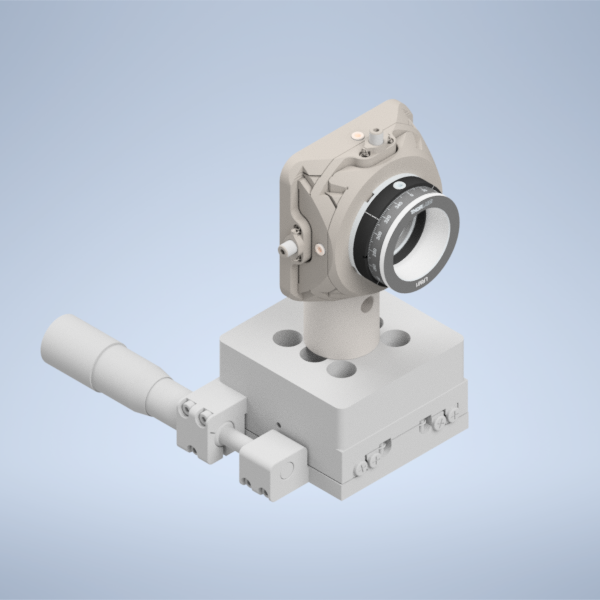
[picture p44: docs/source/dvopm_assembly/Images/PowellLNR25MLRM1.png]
Fixing the Polaris 1XY onto the 1" Polaris Post


    **Figure 30:** Fixing the Polaris 1XY onto the 1" Polaris Post

**Step 7: Screw in the AD9F into the LRM1 mount until it's fully threaded**

Finally, screw in the AD9F fully into the LRM1 mount threading.

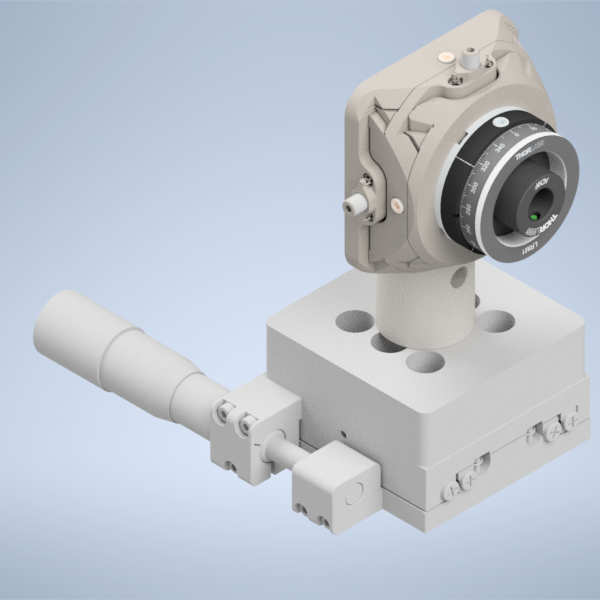
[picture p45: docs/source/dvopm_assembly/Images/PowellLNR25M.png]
Threading the AD9F into the LRM1 mount


    **Figure 31:** Threading the AD9F into the LRM1 mount

There will also an alternate way to mount the 1XY on the baseplate, which is to use XP10X with an actuator XP10X-C1.
You will first mount a 1.5" Polaris Mount with a custom height adapter on the baseplate.
Then you will mount the XP10X on top of the Polaris Mount using dowel pins and 1/4-20 screw, and then mount the Polaris 1XY onto the XP10X-C1 using dowel pins and 8-32 screw.

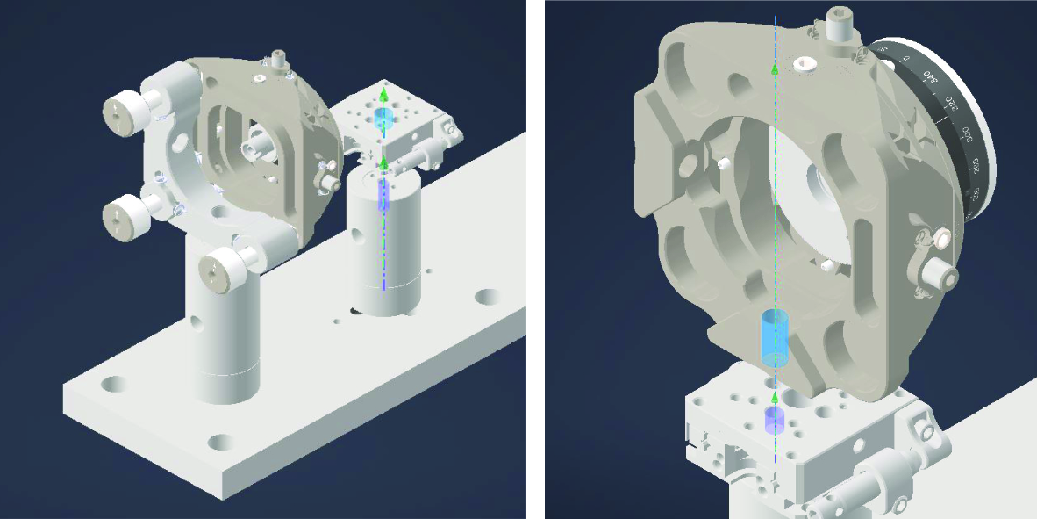
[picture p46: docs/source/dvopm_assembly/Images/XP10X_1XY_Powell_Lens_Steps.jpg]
Mounting the Polaris 1XY onto the XP10X-C1


    **Figure 32:** Mounting the Polaris 1XY onto the XP10X-C1

------------------

Mechanical Slit Assembly
^^^^^^^^^^^^^^^^^^^^^^^^

We use a mechanical slit to control the aperture of the light sheet.
We first mount the VA100CP mechanical slit on the custom adapter usign 3/8" screw, and then mount the custom adapter onto the Polaris Mount using dowel pins and 3/8" screw. Finally, we mount the Polaris Mount onto the baseplate using dowel pins and 1/4-20 screws.
The slit should be placed at the focal plane of the second achromatic doublet, so that it can effectively control the aperture of the light sheet. If you can't find the focus at the mechanical slit, you can play with the position of the powell lens a little using the translation stage it sits on, and you should be able to find the focus at the mechanical slit.

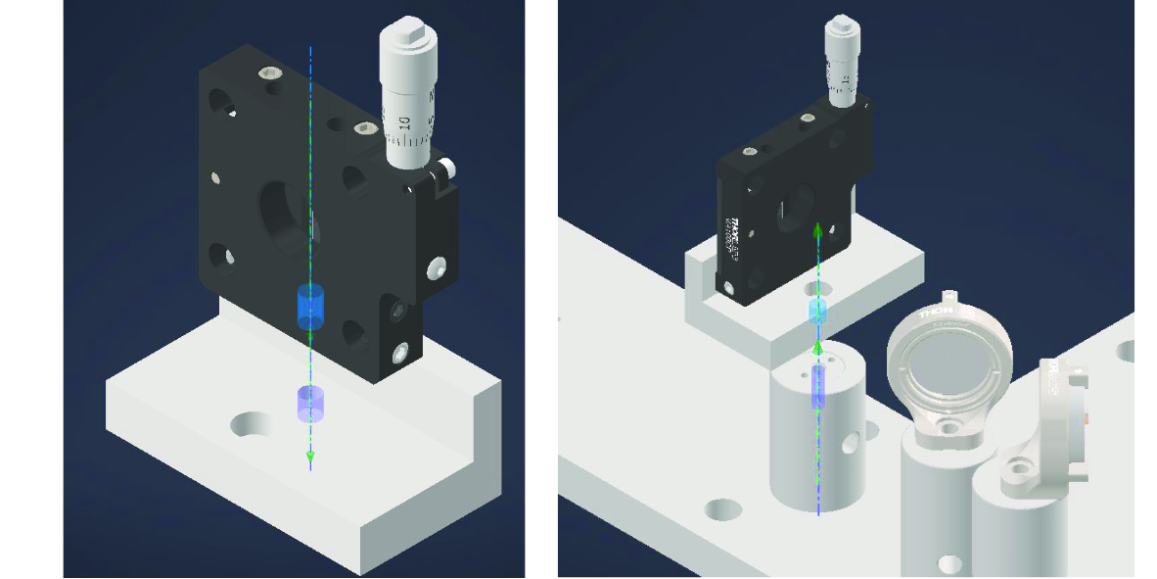
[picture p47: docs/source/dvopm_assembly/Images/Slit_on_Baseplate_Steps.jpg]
Mounting the mechanical slit onto the baseplate


    **Figure 33:** Mounting the mechanical slit onto the baseplate
   
------------------

The final baseplate assembly should look like the figure below.

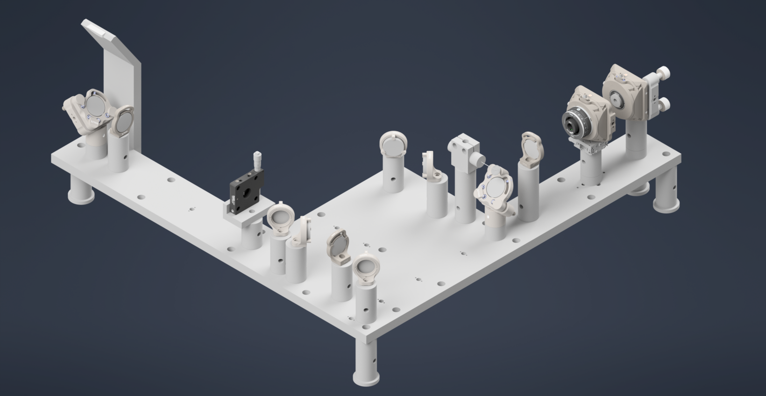
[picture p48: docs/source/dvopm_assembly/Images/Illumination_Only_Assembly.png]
Aligning the mechanical slit with the beam path


    **Figure 34:** Final Assemlby of the Illumination Train on the Baseplate. The optical path is highlighted in yellow.

------------------

Coupling the Illumination Train with the Detection Module
^^^^^^^^^^^^^^^^^^^^^^^^^^^^^^^^^^^^^^^^^^^^^^^^^^^^^^^^^

Finally with both the illumination train and the detection module assembled, we can then couple the illumination train with the detection module. The key is to make sure that the beam from the illumination train is properly reflected by the D-shaped mirror into the detection module, and that it is properly aligned with the optical path of the detection module.

The stage essentially integrates the illumination and detection trains.
The stage assembly includes the following S561-2235B, Dual-LS-50-FTP with LS-5007 and LS-1010-K.

**Important: The height of the stage must be set to over 260mm from the optical table to the bottom surface of the stage**

Place stage over the illumination train 4" away from the pedastal post at the end of the baseplate. For the detection module, use a `PT1B stage <https://www.thorlabs.com/thorproduct.cfm?partnumber=PT1B>`_ with a `MSAP90 bracket <https://www.thorlabs.com/thorproduct.cfm?partnumber=MSAP90>`_ to mount the detection module and place under the stage. Then, you can use the translation stage to adjust the position of the detection module such that the pupil of the objective is nearly in the center of the stage field of view.
The figure below shows the final assembly of the stage with the detection module mounted on it, and the stage placed over the illumination train.

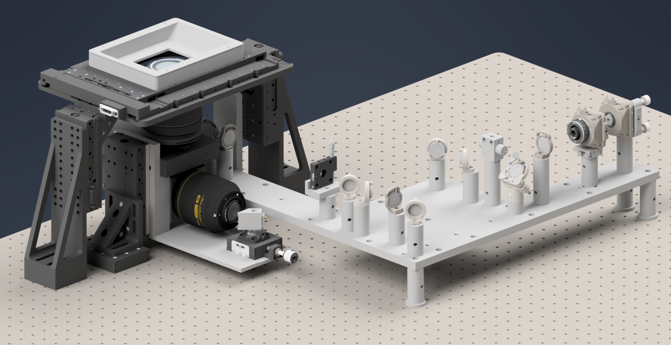
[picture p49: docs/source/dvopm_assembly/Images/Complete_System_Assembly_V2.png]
Final assembly of the stage with the detection module mounted on it, and the stage placed over the illumination train.


    **Figure 35:** Final assembly of the stage with the detection module mounted on it, and the stage placed over the illumination train.

The following figure shows the front view of the complete assembly where the D-Shaped mirror mounted on the oblique side plate launches the beam into the specimen sitting on the stage at an oblique angle.

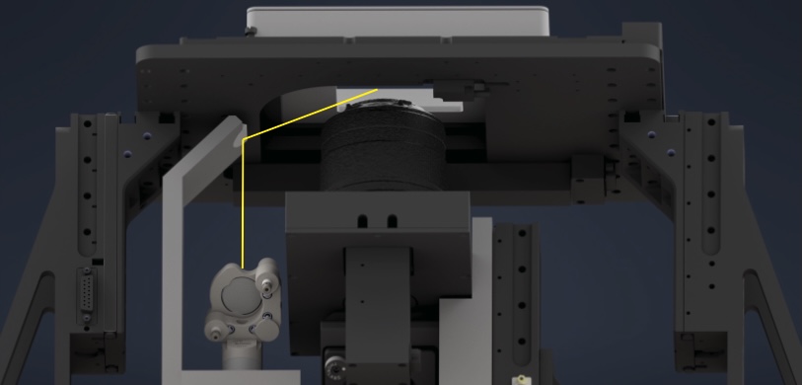
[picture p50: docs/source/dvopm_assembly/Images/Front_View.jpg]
Final assembly of the stage with the detection module mounted on it, and the stage placed over the illumination train.


    **Figure 36:** Final assembly of the stage with the detection module mounted on it, and the stage placed over the illumination train.

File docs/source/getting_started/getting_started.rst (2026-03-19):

.. _gettingstarted-home:

###############
Getting Started
###############

In order to be able to control stage positions, toggle lasers, trigger cameras, and so on,
you first need to set up a connection to your hardware. This guide will walk you through the steps necessary to get your system up and running.

Hardware Setup
______________________

Unlike other microscopy systems, Altair simplifies control by having only one controller: one apparatus to trigger and drive all necessary devices.
This is Applied Scientific Instrumentation's `Tiger Controller <https://www.asiimaging.com/controllers/tiger-controller/>`_,
a modular controller with customizable control cards. Our solution calls for a Tiger Controller with the following cards:

- `TGCOM <https://asiimaging.com/docs/tg1000_info#description>`_ - Allows joystick control and serial communication from the computer.

- 3 stage control cards (X/Y, Z/F, M/N).

- 2 `DAC4 <https://asiimaging.com/docs/tggalvo>`_ cards - Analog signal generators.

- `TGPLC <https://asiimaging.com/docs/tiger_programmable_logic_card>`_ - Programmable logic controller providing custom timing.

- `FW-1000 <https://asiimaging.com/docs/fw_1000>`_ - Filter wheel control.

The order of these cards within the controller does not matter.
The software to run the controller is `navigate <https://thedeanlab.github.io/navigate/index.html>`_.
Navigate supports many microscope configurations, where each configuration is defined by a configuration file.
The provided configuration file will delineate the following configuration:

=========  =======================  =========  =======================
**Axis**   **Device**               **Axis**   **Device**
=========  =======================  =========  =======================
**A**      Remote Focus Voice Coil  **1**      Camera Trigger
**B**      Galvanometer             **2**      Laser Shutter
**C**      Remote Focus Reference   **3**      Stage In*
**D**      Not Used                 **4**      Stage Out*
**H**      405 nm Laser (Analog)    **5**      405 nm Laser (Digital)
**I**      488 nm Laser (Analog)    **6**      488 nm Laser (Digital)
**J**      561 nm Laser (Analog)    **7**      561 nm Laser (Digital)
**K**      638 nm Laser (Analog)    **8**      638 nm Laser (Digital)
=========  =======================  =========  =======================

The stage control card specified for PLC outputs 3 and 4 is the stage that is used for Z-stacks.
This allows stage feedback to dictate when the sample is ready for an image.
In our configuration, the X hardware stage corresponds to the Z stage within the software.
This can be changed to match your stage setup by editing the following part of the configuration file:

.. collapse:: Configuration File

    .. code-block:: yaml

      microscopes:
        microscope_name:
            stage:
              hardware:
                -
                  type: ASI
                  serial_number: 001
                  axes: [x, y, z, f]          # software stages 
                  axes_mapping: [X, Y, Z, F]  # hardware stages

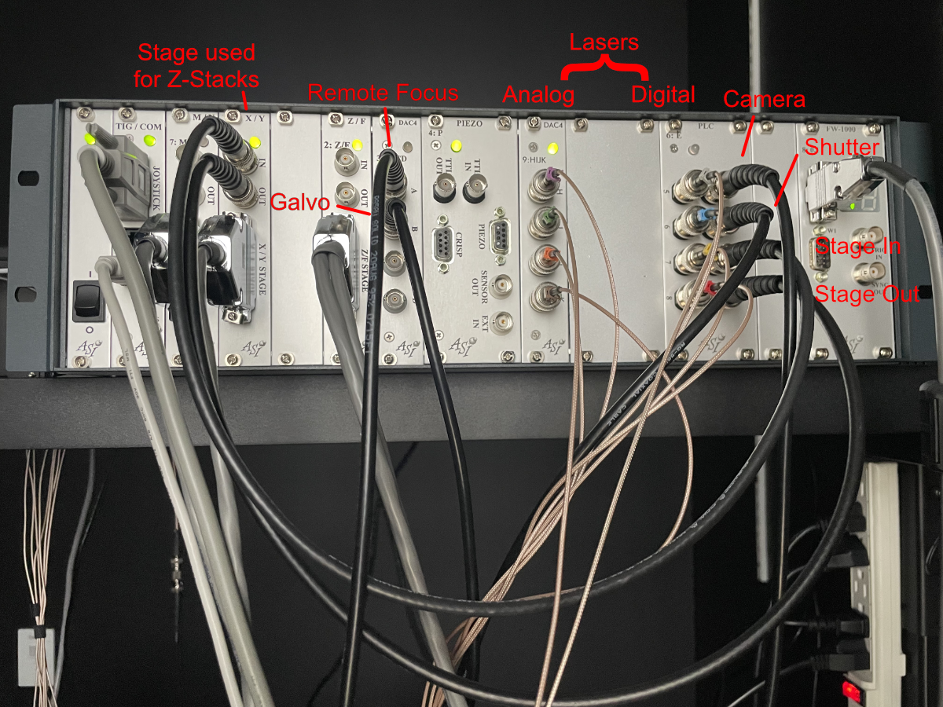
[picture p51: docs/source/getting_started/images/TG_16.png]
Tiger Controller with specified cards for Altair


    **Figure 1:** Tiger Controller with specified cards for Altair

The wiring diagram for the Altair-ASLM with ASI Control is shown below:

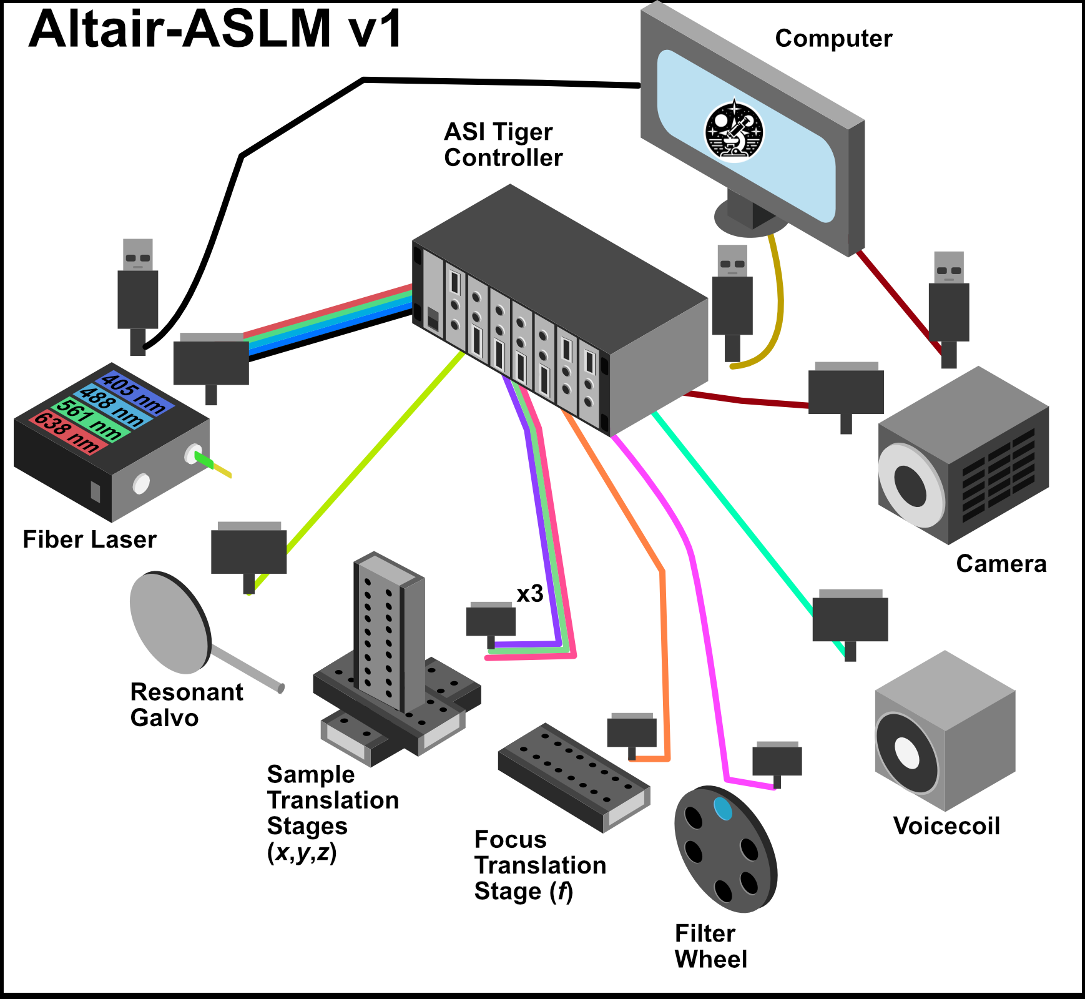
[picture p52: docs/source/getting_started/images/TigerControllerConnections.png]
Tiger Controller Connections


    **Figure 2:** Tiger Controller Connections

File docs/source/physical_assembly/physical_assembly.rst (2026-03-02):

.. _assembly-home:

###################
Microscope Assembly
###################

Parts List and Cost
___________________

A breakdown of all components used in Altair, and the approximate cost, is included in the collapsible sections below:

.. collapse:: Illumination Path

    .. list-table::
       :header-rows: 1

       * - Standard Parts
         - Vendor
         - Purpose
       * - TL20X-MPL
         - Thorlabs
         - Illumination Objective
       * - Polaris-1XY
         - Thorlabs
         - Mounting
       * - Polaris-K1XY
         - Thorlabs
         - Mounting
       * - Polaris-MA45
         - Thorlabs
         - Mirror Mounting
       * - Polaris-P150
         - Thorlabs
         - Mounting
       * - Polaris-P200
         - Thorlabs
         - Mounting for L4
       * - Polaris-P3
         - Thorlabs
         - Mounting
       * - Polaris-P250
         - Thorlabs
         - Mounting
       * - Polaris-P225
         - Thorlabs
         - Mounting
       * - Polaris-P075
         - Thorlabs
         - Mounting
       * - Polaris-P175
         - Thorlabs
         - Mounting
       * - Polaris-B1S
         - Thorlabs
         - Lens Mounting
       * - Polaris-K1S4
         - Thorlabs
         - Mirror Mounting
       * - CFC11A-A
         - Thorlabs
         - Fiber Laser Collimator
       * - P3-405B-FC-1
         - Thorlabs
         - Single Mode Fiber
       * - AC254-080-A-ML
         - Thorlabs
         - L2
       * - AC254-030-A-ML
         - Thorlabs
         - L1
       * - VA100CP
         - Thorlabs
         - Rectangular Aperture
       * - ACY254-075-A
         - Thorlabs
         - L3
       * - PF10-03-P01
         - Thorlabs
         - 1\" Mirror
       * - RSP1
         - Thorlabs
         - Rotation Mount For Cylindrical Lens
       * - AC254-250-A-ML
         - Thorlabs
         - L4
       * - SM1A12
         - Thorlabs
         - Illumination Objective Mounting
       * - 1-Axis 4 kHz Resonant Galvo and Servo
         - Novanta
         - Galvo Mirror
       * - TGPOW-12-3
         - ASI
         - Galvo Low Noise Power Supply +12 V 3 A
       * - Polaris B1F
         - Thorlabs
         - Mount for Mirror 2
       * - ID12
         - Thorlabs
         - Mounted Circular Iris (12 mm Max Aperture)
       * - L4CC
         - Oxxius
         - Multicolor Laser Source
       * -
         -
         -
       * - **Custom Machined Parts**
         - **Vendor**
         - **Purpose**
       * - RSP1 Polaris Adapter
         - Xometry
         - Polaris Adapter for RSP1 Cylindrical Lens
       * - Illumination Baseplate
         - Xometry
         - Baseplate
       * - Galvo Holder
         - Protolabs
         - Galvo Mounting
       * - VA100CP Polaris Adapter
         - Xometry
         - Aperture Mounting
       * - IDA12 Polaris Adapter
         - Xometry
         - Polaris Adapter for ID12 Iris

.. collapse:: Detection Path

    .. list-table::
       :header-rows: 1

       * - **Part**
         - **Vendor**
         - **Purpose**
       * - N25X-APO-MP
         - Thorlabs (Nikon)
         - Detection Objective
       * - LS-100-AMCCH
         - ASI
         - 100 mm Linear Focusing Stage
       * - TGDCM2
         - ASI
         - 2-Axis Stage Control Card
       * - C60-EXT-15
         - ASI
         - 15 mm Tube Extension
       * - RAO-0051
         - ASI
         - M32x0.75 Threaded Sleeve
       * - FW-0002-8
         - ASI
         - 8-Position Filter Wheel
       * - FW-C-MNT-K1
         - ASI
         - Filter Wheel to MIM Adapter Kit
       * - TGFW
         - ASI
         - Filter Wheel Control Card
       * - C60-TUBE-400
         - ASI
         - 400 mm Achromatic Tube Lens
       * - C13440-20CU
         - Hamamatsu
         - ORCA Flash4.0 V3 Camera
       * - Semrock Brightline Filter 605/15-25 nm
         - IDEX
         - Filter
       * - Semrock Brightline Filter 445/20 nm
         - IDEX
         - Filter
       * - Semrock Brightline Filter 676/29 nm
         - IDEX
         - Filter
       * - Semrock Brightline Filter 529/24-25 nm
         - IDEX
         - Filter

.. collapse:: Sample Positioning

    .. list-table::
       :header-rows: 1

       * - **Part**
         - **Vendor**
         - **Purpose**
       * - KBT1X1T
         - Thorlabs
         - Magnetic Mount for Sample Holder Top
       * - KBB1X1
         - Thorlabs
         - Magnetic Mount for Sample Holder Bottom
       * - LS-5012
         - ASI
         - Breadboard Adapter for Translation Stages
       * - LS-5013
         - ASI
         - Right Angle Bracket for Translation Stages
       * - DV-6010-C
         - ASI
         - Dovetail Mount Pair
       * - LS-50-AMCLLS
         - ASI
         - 50 mm Linear Stage with Stainless Steel Slide
       * - LS-100-AMERL
         - ASI
         - 100 mm Linear Stage, 16 TPI, Extended, Right
       * - LS-50-AMELL
         - ASI
         - 50 mm Linear Stage
       * - TGADEPT
         - ASI
         - Piezo Control Card
       * - HS1.100
         - PiezoConcept
         - 100 Micron Piezo Stage
       * - ADAPTHS1BB
         - PiezoConcept
         - Adapter Plate for PiezoConcept HS1
       * -
         -
         -
       * - **Custom Machined Parts**
         - **Vendor**
         - **Purpose**
       * - Angle Bracket Adapter
         - Xometry
         - Mounting the piezo to ASI translation stages at an angle
       * - 5 mm Coverslip Holder
         - Xometry
         - Sample holder for 5 mm Coverslips
       * - 5 mm Coverslip Holder Adapter
         - Xometry
         - Adapter to mount coverslip holder onto KBT1X1T linearly

.. collapse:: Shared Equipment

    .. list-table::
       :header-rows: 1

       * - **Part**
         - **Vendor**
         - **Purpose**
       * - TG16-BASIC
         - ASI
         - Tiger Controller - 16 Bay System
       * - T3283
         - Thorlabs
         - BNC Adapter (F-F)
       * - PAA272R
         - Thorlabs
         - SMB F to BNC M cable adapter
       * - CA2106
         - Thorlabs
         - BNC to Terminal Pin Cable
       * - PCIe-6738
         - NI
         - Data Acquisition Card
       * - SHC68-68-A2
         - NI
         - Test Cable Assembly
       * - SCB-68A
         - NI
         - Noise Rejecting Terminal Block
       * - SX6300
         - Colfax International
         - Colfax SC6300 Workstation
       * - 14UD-42X-24
         - TMC
         - Ultradamp Vibration Isolation with Casters
       * - 784-736-02R
         - TMC
         - 36x60x18\" Performance Series Optical Top Table

.. collapse:: Total Cost

    .. list-table::
       :header-rows: 1

       * - **Section**
         - **Cost (USD)**
       * - Illumination Path
         - \$42,419.67
       * - Detection Path
         - \$61,635.82
       * - Sample Positioning
         - \$18,869.78
       * - Shared Equipment
         - \$32,300
       * - **TOTAL**
         - **\$155,224.78**

---------------

Illumination Path
_________________

Our baseplate design was made with ease of assembly in mind. The basic process involves aligning Polaris posts with
dowel pins and screwing them using 1/4"-20 Screws in at the predetermined hole locations on the breadboard.
This general process is depicted below:

General process for baseplate assembly

    **Figure 1:** General process for baseplate assembly

To either mount the baseplate onto an optical table or onto separate posts, the process is similar in that
just requires screwing 1/4"-20 screws into either an optical breadboard or onto separate posts at the four corner
holes. For our system, we opted to mount our illumination baseplate on 1.5" tall `1" diameter Thorlabs pedestal posts
<https://www.thorlabs.com/newgrouppage9.cfm?objectgroup_id=851>`_. As a general note, having the illumination path
elevated instead of affixed directly into the table is both helpful to enable access to mounting and unmounting the
illumination optics as well as ensuring that the illumination objective and detection objective are able to be
aligned vertically with each other.

General process to place posts on baseplate corners

    **Figure 2:** General process to place posts on baseplate corners

---------------

Ordering Custom Parts from Xometry
^^^^^^^^^^^^^^^^^^^^^^^^^^^^^^^^^^^

We utilize a number of different custom fabricated elements in our completed system. There are a number of
different companies available for this, and we opted for Xometry. The basic ordering process we go through is as
follows:

    1. Begin by creating an account with Xometry
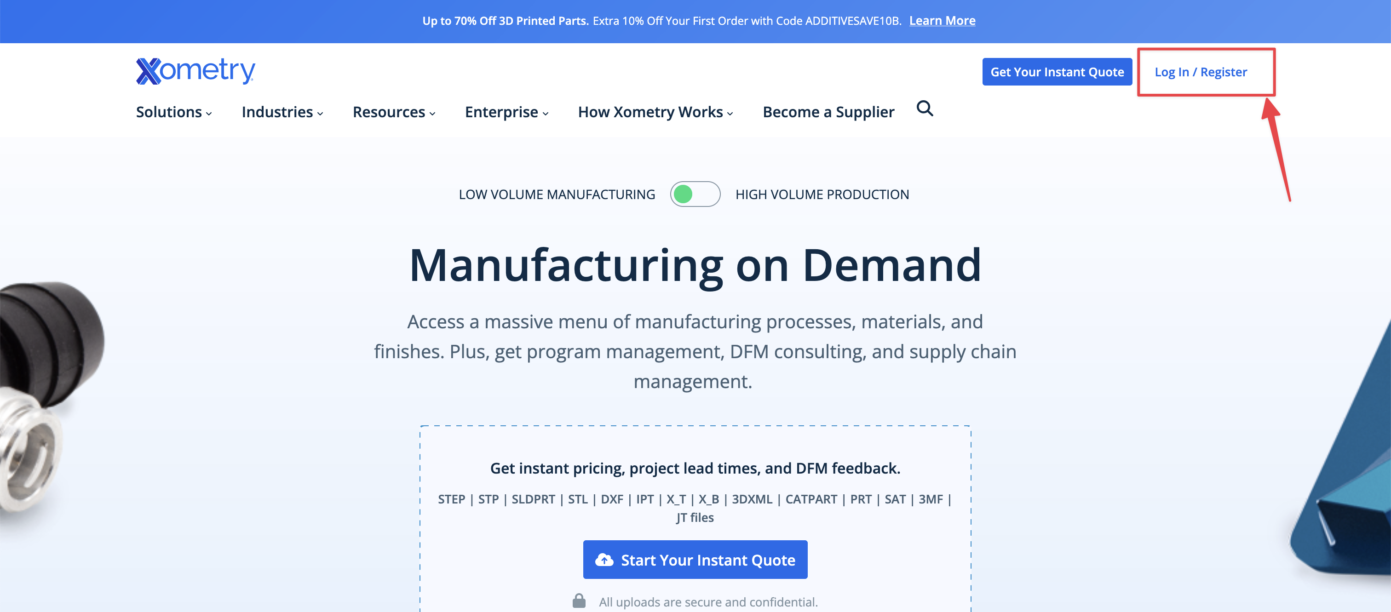
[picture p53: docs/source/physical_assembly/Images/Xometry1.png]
Xometry Ordering Process 1
        
    2. Start a quote by uploading your desired file (in .stp format)
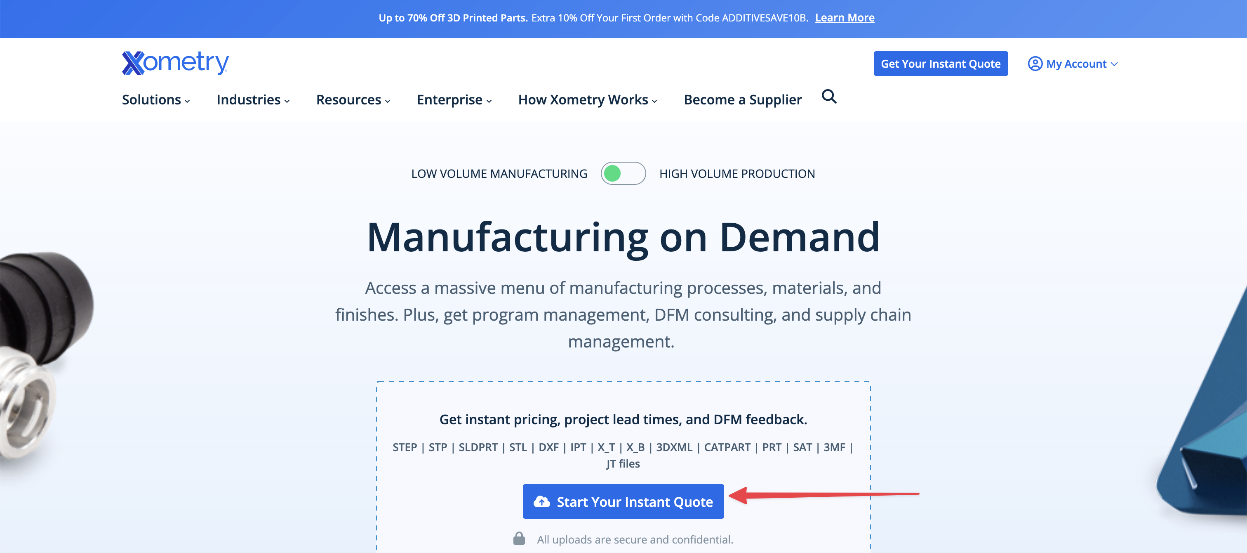
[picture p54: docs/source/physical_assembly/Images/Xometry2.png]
Xometry Ordering Process 2
        
    3. Edit the configuration
        Xometry Ordering Process 3
    4. Adjust the fabrication process to be CNC machining
        Xometry Ordering Process 4
    5. Select Aluminum 6061-T6 as the material for machining
        Xometry Ordering Process 5
    6. Adjust the finish to be bead blasted
        Xometry Ordering Process 6
    7. If you have a part that uses threads or tapped holes, select that option and upload associated PDF drawings
        Xometry Ordering Process 7
    8. Select shipping details and checkout

---------------

Mounting Lenses
^^^^^^^^^^^^^^^

Mounting lenses into a Polaris lens mount and onto an associated post is a fairly straightforward process. The
general flow is shown in the image below, where first the flatter face of the desired lens should be placed such that
it is touching the metal boundary on the lens mount itself. Then the lens should be fixed into place by screwing the
lock screw on the top of the lens mount. With the lens secured in the mount, then two dowel pins should be placed in
the appropriate holes on the Polaris post, and then the lens mount should be placed such that the two holes on the
lens mount align with the pins on the Polaris post. Then the lens mount should be anchored into place by screwing it
into the Polaris post. Additional information can be found at `Thorlabs <https://www.thorlabs.com/newgrouppage9.cfm?objectgroup_id=10056>`_.

General process for mounting a lens into a Polaris holder and onto a post

    **Figure 3:** General process for mounting a lens into a Polaris holder and onto a post

---------------

Initial Laser Collimation and Alignment
^^^^^^^^^^^^^^^^^^^^^^^^^^^^^^^^^^^^^^^

When first assembling the system, ensuring proper output collimation from the fiber laser source is critical. There are multiple checks that one can take for this step, but we utilize a combination of a `shear-plate interferometer <https://www.thorlabs.com/newgrouppage9.cfm?objectgroup_id=2970>`_ and two pinhole apertures placed at opposite ends along the length of the baseplate. Shear-plate interferometers are designed to split and interfere an input beam of coherent light, such that when the beam is collimated there are interference fringes aligned vertically with a reference line. The fiber laser collimator we used for this system is the `Thorlabs CFC11A-A <https://www.thorlabs.com/thorproduct.cfm?partnumber=CFC11A-A>`_, which features an adjustable barrel which controls the position of collimation optics within the element.

The basic assembly process involves first inserting and fixing the CFC11A-A into a Thorlabs AD15S2 adapter, which allows it to then be mounted into a 2.5" Polaris K1XY mount. This assembly is then mounted onto the respective Polaris post at the start of the baseplate. The fiber laser source is then able to be directly mounted into the CFC11A-A, making sure that the protrusion on the fiber wire aligns with the open section of the CFC11A-A port. The basic process of ensuring collimation then involves turning on the laser source, and placing the shear-plate interferometer such that the input port aligns with the output of the laser unit. Then, by slowly adjusting the barrel of the CFC11A-A and observing the interference fringe orientations along the top display of the interferometer, one is able to adjust the beam until it is properly collimated.

Shear Plate interferometer and collimator lens

    **Figure 4:** Shear Plate interferometer and collimator lens

With the beam collimated, the process of beam alignment involves adjusting the position control knobs on the K1XY to have the beam pass through two pinhole apertures along the optical path. The height of the initial laser output is designed to be at 3.75" above the top surface of the baseplate, so selecting appropriate post heights for the apertures such that their centers rest at 3.75" is essential. In our case, we use `Thorlabs ID12 <https://www.thorlabs.com/thorproduct.cfm?partnumber=ID12>`_ pinhole apertures, so using a post height of 3.25" will ensure that they are at the proper height for alignment. We designed a `custom ID12 to Polaris adapter <https://github.com/TheDeanLab/altair/tree/main/downloads/common/cad>`_ to ensure the aperture is at the proper height and properly aligned along the designated Polaris axis. When using this method, the ID12 to Polaris adapters can be mounted directly onto the holes designated for L1 and the illumination objective, depicted below, to cover the length of the baseplate. With the pinholes placed, the process becomes iterative by making small adjustments on the K1XY tip/tilt knobs and XY position screws until the beam passes through both pinholes.

Performing beam alignment across the baseplate

    **Figure 5:** Performing beam alignment across the baseplate

---------------

Mounting of Optic Posts
^^^^^^^^^^^^^^^^^^^^^^^

After ensuring basic collimation and alignment of the laser system, the next step is mounting the appropriate Polaris
post size for each optical element in the system. The overall breakdown of which size posts went with each hole
location is listed below. Where holes (3), (4), and (10) are placements for optional elements in the system. (3) is
meant for the placement of an adjustable pinhole aperture, where the same ID12 to Polaris Adapter system used in
the alignment step can be placed. Otherwise a 0.5" post holder can be placed here, and then the ID12 or one's pinhole
aperture of choice can be mounted on a 0.5" post. (4) is dedicated placement for an electronic shutter in the event
that the laser being used for the system isn't directly controlled via a computer, and helps to ensure that laser
light is not photobleaching a sample unless imaging is taking place. (10) is dedicated space for a neutral density
(ND) filter, in the event that the power of the laser used needs additional reduction not directly controlled
through the laser controls itself.

Schematic of which holes use which post heights

    **Figure 6:** Schematic of which holes use which post heights

---------------

Mounting of Optics
^^^^^^^^^^^^^^^^^^

With the posts in place, the next step involves mounting the optics elements themselves onto the posts. When mounting elements (6), the VA100 rectangular aperture, and (7), the RSP1 rotation mount, it should be noted that the corresponding element should first be fixed onto their respective Polaris adapter and then onto the Polaris posts. In addition, take measures to mount the 45 degree mirror (9) fully prior to mounting the resonant galvo to ensure that the galvo is not accidentally hit during installation of the 45 degree mirror.

To construct the 45 degree mirror assembly, first mount the Polaris K1S4 onto the Polaris-MA45 45 degree mounting adapter, and then place a 1" diameter mirror into the K1S4 and secure it using the K1S4 mounting screw.

To construct the illumination objective assembly, first mount the Polaris 1XY onto its respective 1.5" post. The threading of the 1XY (SM1) does not match that of our illumination objective used (M25x0.75), so an SM1A12 adapter must first be installed onto either the 1XY or the illumination objective. Then, the objective can be mounted onto
the 1XY.

---------------

Final Alignment Adjustments
^^^^^^^^^^^^^^^^^^^^^^^^^^^

Once all the optics have been properly mounted, the final step for ensuring a working illumination path is to center
the beam after the 45 degree mirror onto the center of back lens surface of the illumination objective. The primary
method of doing this is through adjusting the xy tip/tilt knobs on the K1S4 Polaris mount that houses the 45 degree
mirror.

---------------

Detection Path
______________

Detection Path Assembly
^^^^^^^^^^^^^^^^^^^^^^^

Our detection path consists of our Nikon N25X-APO-MP detection objective, Hamamatsu ORCA Flash4.0 V3 Camera, ASI
C60-TUBE-400 tube lens, and ASI FW-0002-8 8-position filter wheel unit. These components are mounted together and
affixed onto an ASI LS-100-AMCCH translation stage for focus control. We currently use a prototype detection path
baseplate (available here) as a mounting stage for these elements and the sample chamber; however, this additional
baseplate is still undergoing design iterations and is not critical for a functional detection path.

We utilize two additional custom adapter elements in the construction of the detection path: a shell casing around
the tube lens that mounts to the translation stage and an adapter for the translation stage to mount it to an optical
breadboard table. The height thicknesses of these elements were chosen such that the height of the detection
objective center should match that of the illumination objective (which with the 1.5" tall posts our illumination
baseplate rests on is 4.75" above the optical table surface). These elements can be custom machined if desired;
however, we have found 3D printed PLA variants to perform their functions effectively as well.

The assembly of the detection path begins with the translation stage and its associated breadboard adapter
(available here in two variants, based on whether or not one is using the 0.5" thick detection path baseplate):

    1. Turn the translation stage upside-down
    2. Place the breadboard adapter upside-down on top of the inverted translation stage (such that the raised
       platform of the adapter is touching the bottom side of the translation stage)
    3. Align the recesses on the bottom of the adapter with the holes on the bottom of the translation stage
    4. Fix the adapter onto the translation stage by screwing M6 screws into the recesses aligned with the
       translation stage holes.

Schematic of the translation stage breadboard adapter

    **Figure 7:** Schematic of the translation stage breadboard adapter

The next step is flipping the translation stage assembly right side up again, and then fixing the first of two halves
of the tube lens adapter onto the top of the translation stage:

    1. Place the tube lens adapter half onto the top of the translation stage such that the block with two sets of
       five recessed holes is touching the top of the translation stage.
    2. Align the recess holes on the adapter with the holes on the top of the translation stage.
    3. Fix the adapter onto the translation stage by screwing M6 screws into the aligned recess holes

Schematic of the tube lens to translation stage adapter

    **Figure 8:** Schematic of the tube lens to translation stage adapter

Next, we'll focus on assembling the tube lens and filter wheel:

    1. Take the MIM to Filter wheel adapter and fix it onto the front port of the filter wheel using the associated
       screw ports
    2. With the adapter fixed, now screw the 400 mm tube lens into the adapter.

Schematic of the filter wheel port for the tube lens

    **Figure 9:** Schematic of the filter wheel port for the tube lens

In order to fix our detection objective onto the tube lens, we must first prepare an extension and threading adapter:
    1. Take the C60-EXT-15 15 mm Tube extension piece and place the RAO-0051 M32x0.75 threaded sleeve inside
    2. Using the screws on the top of the extension piece, fix the threaded sleeve in place
    3. Insert/screw the extension piece into the front of the tube lens.

Showcase of the screws used to secure the thread adapter for the tube lens

    **Figure 10:** Showcase of the screws used to secure the thread adapter for the tube lens

The tube lens assembly is now ready to be fixed onto the translation stage assembly:
    1. Place the tube lens assembly such that the tube lens lies within the curved region of the tube lens adapter
    2. While there isn't an exact science to the relative placement of the tube within the adapter, try to position
       it such that more of the tube is extended out on the side where the objective will be mounted (our setup is shown
       below for reference).
    3. Place the second half of the tube lens adapter such that the curved side fits onto the tube lens and position
       it such that the holes of both halves of the adapter align with each other.
    4. Using your choice of either M6 or 1/4"-20 screws and associated washers/nuts, place the screws with a washer
       placed on them first into the aligned holes of the adapter. We used 4 of the adapter holes on each side, but
       more can be used for extra security if desired.
    5. Screw a washer onto each of the screws until they're secured against the bottom lip of the adapter.

Example of tube lens mounted in the corresponding adapter

    **Figure 11:** Example of tube lens mounted in the corresponding adapter

The detection path assembly can now be fixed into place onto either the detection path baseplate or the optical
table. Keep in mind this process is meant to place the unit roughly where it should be; finer
adjustments will be made afterwards:

    1. Using the mounting holes on the translation stage assembly, place the assembly such that the edge of the
       translation stage adapter facing the illumination path is roughly 9-10" away from the location of the
       illumination objective.
    2. Using the adjacent edge of the translation stage adapter (the one that should be perpendicular to the
       orientation of the illumination path), try to align the side of the adapter with the mounting hole of the
       illumination objective.
    3. Screw the translation stage adapter into either the optical table or the detection path baseplate (we
       recommend using `Thorlabs 1" Spacers <https://www.thorlabs.com/newgrouppage9.cfm?objectgroup_id=851>`_ in place
       of washers here).

Example of our setup for securing the translation stage to breadboard adapter onto our detection path
          baseplate
    :width: 300px

    **Figure 12:** Setup for securing the translation stage to breadboard adapter onto our detection path baseplate

With the assembly fixed in place, the camera can then be screwed into the filter wheel:
    1. Align the front thread of the camera with the back port of the filter wheel
    2. Screw the camera into the filter wheel until there is resistance
    3. Slowly adjust the camera tilt until the top surface is leveled (we use a bubble leveling tool for this, shown
       below)

Mounting of the camera

    **Figure 13:** Mounting of the camera

The final steps to assemble the detection path are to screw the detection objective into the front of the tube
lens and attach all associated wires to the camera, filter wheel, and translation stage. If there's not enough
clearance between the front of the tube lens and the sample chamber to screw in the detection objective, the
translation stage might need to be wired up first and translated backwards manually using either navigate or the
Tiger Control Panel software.

---------------

Detection Path Positioning
^^^^^^^^^^^^^^^^^^^^^^^^^^

To position the detection path correctly, there are two primary steps: first ensuring the detection objective slides into the correct port on the fixed sample chamber, and then ensuring that the light sheet is centered in the FOV of the camera, typically done by adding fluorescein into the water-filled chamber.

**Step 1: Ensuring the detection objective slides into the sample chamber port**
    1. It's recommended to start with your detection path translation stage set far enough back such that there is anywhere from 0.5-1" or more of space between the front of the detection objective and the sample chamber.
    2. Within navigate or the Tiger Controller software, start to slowly move the objective forward (initially, increments of 1000 µm should be okay, but as the objective approaches the port the distance should be significantly lowered to 100 µm or below to ensure the objective isn't damaged).
    3. If the objective isn't centered properly, the screws/nuts on the translation stage to breadboard adapter (see figure 12) can be loosened slightly and the detection path assembly can be carefully positioned horizontally, taking care that the unit isn't tilted at an angle going into the objective port, and then re-tightened.

Once the detection objective properly translates into its port, the tilt alignment can be further refined by slowly translating the detection objective forward toward the illumination objective, taking great care that they don't touch each other. If there is a significant tilt in the detection path compared to the illumination path, it should be fairly evident in the diagonal space between the objectives (ideally, it should look roughly equal in width between the two objectives). An example of the relative position of our objectives when the detection objective is properly placed at the focus of the illumination objective is shown below to give a visual reference for users.

Once the position of the detection objective is acceptable, further refinement of its position can be done by first filling the chamber with water and then adding roughly ~100 µL of fluorescein into the chamber. Fluorescein is useful as a visualization tool to see the beam coming out of the illumination objective with the naked eye. With fluorescein in the chamber, the position of the detection objective can be translated to align with the focus of the beam itself (shown below).

Physical alignment of the detection objective

    **Figure 14:** Physical alignment of the detection objective

**Step 2: Focus refinement**
    With the detection objective roughly in the correct location, further refinement is done by turning on the camera and imaging the fluorescein light sheet to find the focus by adjusting the focus translation stage in small increments (50 µm for large movements, 1-5 µm for small movements). The goals during this step are to ensure that the detection objective focus is at the focus of the illumination objective, to make sure the light-sheet focus is centered on the image FOV from the camera, and that the light sheet is aligned vertically in the image FOV.

    Finding the focus is often something that just comes with experience of using the system itself; however, here are some general methods to follow that can help get one's bearings:
        1. In general, as the detection objective approaches the light-sheet focus, an envelope of light should start to appear (see below). Ideally, this envelope will be horizontal across the FOV. If it is not horizontal or has some tilt, adjust the tip/tilt of the 45 degree mirror and the rotation of the cylindrical lens. In addition, this envelope should ideally be centered vertically in the FOV, which can be set by adjusting the y adjustment screw on the illumination objective mount.
        2. Toward the focus location, a dark vertical region with horizontal striations should appear. Once this region is visible, use small translation distances (~1 µm or finer) to find the position that makes both the vertical region and horizontal striations look as sharp as possible.
        3. If the dark region isn't centered on the image FOV, adjusting the x and y adjustment screws on the illumination objective mount and making slight horizontal translations on the detection path can help.
        4. In general doing these adjustments in small increments is helpful, as once adjustments to the various elements may require readjusting the focus translation stage position to keep track of the focus.

Breakdown of the light sheet focus within navigate

    **Figure 15:** Breakdown of the light sheet focus within navigate

---------------

Optomechanics
_____________

Visualization of Axes Mapping
^^^^^^^^^^^^^^^^^^^^^^^^^^^^^

In our system we have 5 different translation stages at work: the standard x, y, and z axes, an additional stage along the z axis to control the focus of the detection path (f), and an axis associated with the piezo positioned such that its normal is 60.5 degrees away from the y-axis.

Layout of how the axes of the system are mapped

    **Figure 16:** Layout of how the axes of the system are mapped

.. note:: **Coordinate System Differences**

   The coordinate axes used in **optical simulations** differ from those in the **physical microscope system**
   controlled by **navigate**. This discrepancy arises from **standardized axis conventions** in Zemax versus
   those historically used in our previous systems. Users should be mindful of this distinction when interpreting
   simulation results versus real-world microscope operation. The differences are illustrated below:

   Difference in coordinate axes for simulation and physical setup

---------------

The Piezo Angle Mount
^^^^^^^^^^^^^^^^^^^^^

We designed a custom angled mount for our `PiezoConcept HS1 piezo <https://piezoconcept-store.squarespace.com/1-axis/p/hs1>`_ in order to scan our sample easily between our two objectives by translating a single motorized unit (in this case the piezo), instead of having to calculate and program the movement of two translation stages in tandem for both the y and z directions. The anatomy of our angled mount is broken down in the figure below, where there are four translation-stage mounting holes to attach the unit to an ASI translation stage, nine piezo mounting holes that correspond to the mounting scheme of our piezo unit, as well as four through-holes and a window for ease of access for the mounting process. We provide the CAD files for this mount `here <https://github.com/TheDeanLab/altair/tree/main/downloads/common/cad>`_, and have had success using both 3D-printed and aluminum-machined versions of the unit. It is recommended to first mount the angle mount onto the translation-stage unit before mounting the piezo on the angle mount to ensure access to all through-holes.

Breakdown of our custom angle piezo angle mount

    **Figure 17:** Breakdown of our custom angle piezo angle mount.

The installation of our custom angled piezo mount is designed to be directly compatible with ASI translation stages. ASI translation stages feature M6 hole pairs that are spaced along the length of the translation stage at intervals dependent on the specific stage one is using. The mounting process involves aligning these 4 holes with 4 of the M6 holes on the translation stage and screwing them in. For ease of screwing in the base, there are four through holes on the angled face of the mount shown in B that a screwdriver is able to pass directly through to screw as shown in C. An alternative method of mounting is shown in D, where the window on the back of the angle mount is able to be screwed through as well.

General process for mounting our piezo angle mount onto an ASI translation stage

    **Figure 18:** General process for mounting our piezo angle mount onto an ASI translation stage

---------------

Sample Holder Design
^^^^^^^^^^^^^^^^^^^^

Our sample holder design is built for imaging cells on a `5 mm coverslip <https://www.fishersci.com/shop/products/5mm-cover-slip-german-glass/50949439>`_, and is shown below. The design features a clamp-like method of securing the 5 mm coverslip in place, where the coverslip rests in an inset region and the clamp is screwed in via an M1.6 screw in the back of the holder. All associated files for this design and other custom parts can be found `here <https://github.com/TheDeanLab/altair/tree/main/downloads/common/cad>`_.

5 mm coverslip sample holder design

    **Figure 19:** 5 mm coverslip sample holder design.

---------------

Assembling the Magnetic Sample Mount
^^^^^^^^^^^^^^^^^^^^^^^^^^^^^^^^^^^^

As a safeguard against the sample crashing into either the illumination or detection objective during sample positioning or imaging, we opted to incorporate a magnetic mount for our sample holder. We use a Thorlabs KBT1X1T and KBB1X1 as our magnetic mount pair, and then mount our sample holder onto the KBT1X1T using a `custom adapter <https://github.com/TheDeanLab/altair/tree/main/downloads/common/cad>`_. The KBB1X1 is affixed to the piezo using an M2.5 screw, and using a small leveling tool (shown below) during this step is helpful to ensure that the magnetic base is mounted as level as possible for the imaging process.

Basic assembly of magnetic sample holder mount

    **Figure 20:** Basic assembly of magnetic sample holder mount

---------------

Optoelectronics
_______________

Wiring Diagram
^^^^^^^^^^^^^^

Our complete microscope assembly features a variety of different optoelectrical and optomechanical elements. These
elements are primarily controlled via our NI DAQ (PXIe-6738) or our ASI Tiger Controller (TG16-BASIC), which are then
controlled via navigate during the imaging process. The diagram below depicts how these elements are wired together,
as well as an individual pinout designation table for the pin configurations we used on our DAQ.

Wiring diagram for the Tiger Controller, DAQ, and associated elements.

    **Figure 21:** Wiring diagram for the Tiger Controller, DAQ, and associated elements.

---------------

Piezo Setup & Troubleshooting
^^^^^^^^^^^^^^^^^^^^^^^^^^^^^

On the PCI Board, connect the positive and negative wires  to the corresponding analog output (AO) you want, in our case
we used AO 0, so we connected the positive wire to pin 10 and the ground to pin 11, then plug the BNC cable connected to
those wires into the EXT IN input on the Tiger controller panel corresponding to the piezo.

How to find the Device Pinout panel

    **Figure 22:** How to find the Device Pinout panel in NI MAX.

Plug the piezo cable into the PIEZO input on the Tiger controller panel corresponding to the piezo, and verify the range of the piezo in the Tiger Controller software:

.. code-block:: none
   :caption: Verifying Piezo Range in Tiger Controller Software

   # Verify the range of the piezo in the Tiger controller software
   5 cca x?

   # Example output:
   :A  Q:P1
   23 P 1 100um RANGE
   24 P 2 200um RANGE
   35 P S 150um RANGE
   36 P 3 300um RANGE
   37 P 5 500um RANGE
   34 P f 50um RANGE
   25 P 4 350um RANGE:N-4

This tells us that our piezo (Panel 5/Q) corresponded to P1, or a 100 µm range, but ASI requires the piezo to be
set to a 50 µm range to be initialized. To change this, we used the command ``5 cca x = 34`` and
power cycled the controller. Once the controller was powered back on, we verified the range again with the ``5 cca x?``

.. code-block:: none
   :caption: Verifying Piezo Range in Tiger Controller Software

   # Verify the range of the piezo in the Tiger controller software
   5 cca x?

   # Example output:
   :A  Q:Pf
   ...

Now we can see that the piezo is set to the correct range (Pf). With that verified, now confirm that the voltage output from the PCI Board is working:

| 1. Put the BNC cable input currently in EXT IN on the Tiger control panel into the input of the oscilloscope instead.
| 2. Go to the test panels for the PCI board in NI MAX.

How to find the Test Panels panel

    **Figure 23:** How to find the Test Panels panel in NI MAX.

| 3. Set the voltage mode to sinewave generation.
| 4. Set the voltage range to be between 0 to 10 V.
| 5. Set the frequency to a desired value (we ended up setting it relatively high at 10,000 Hz for ease of viewing on the oscilloscope).

How to find the Test Panels panel.

    **Figure 24:** How to generate analog output voltages with NI MAX for testing purposes.

With the voltage output of the PCI board verified, plug the PCI Board voltage cable output back into the EXT IN slot and
verify that the position output of the Piezo reads similarly on the oscilloscope:

    1. Plug a BNC cable into the SENSOR OUT connection on the Tiger controller panel.
    2. Plug the other end of that cable into the oscilloscope.
    3. Verify that a sinewave output is seen on the oscilloscope.

If the PCI Board voltage is working as intended but the piezo position output doesn't seem to work, try ensuring that
the piezo is set in `External Input mode and not Controller Input mode <https://asiimaging.com/docs/commands/pm>`_:

    1. Use the ``PM Q?`` (Our piezo corresponds to Q) command:
        - the output was ``Q = 0`` originally, telling us that it's in Controller Input mode
    2. Use the ``PM Q = 1`` command to set the piezo into External Input mode:
        - now the output of ``PM Q?`` is ``Q = 1``

Another important step is to ensure that the configuration file associated with navigate is appropriately set up for your piezo. This involves setting the correct axis and voltage-to-distance mapping for the piezo. As an example our configuration file for navigate looks like the following for setting up our piezo:

Navigate configuration file for the piezo.

    **Figure 25:** Navigate configuration file for the piezo.

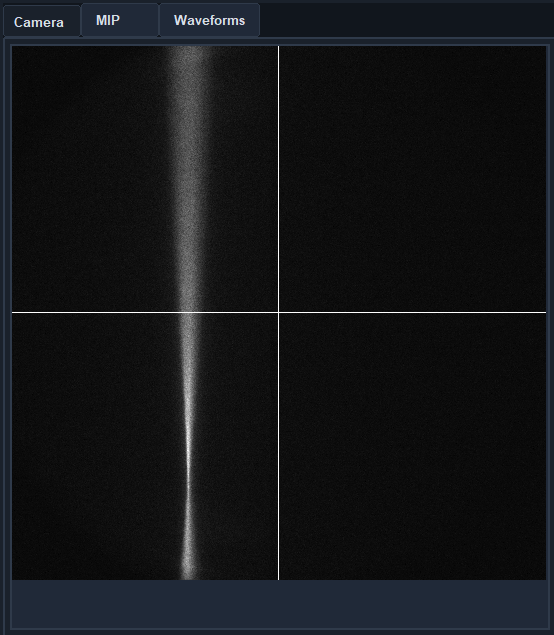
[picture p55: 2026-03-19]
docs/source/baseplate2_alignment/Images/assembly/beam_amplitude.png

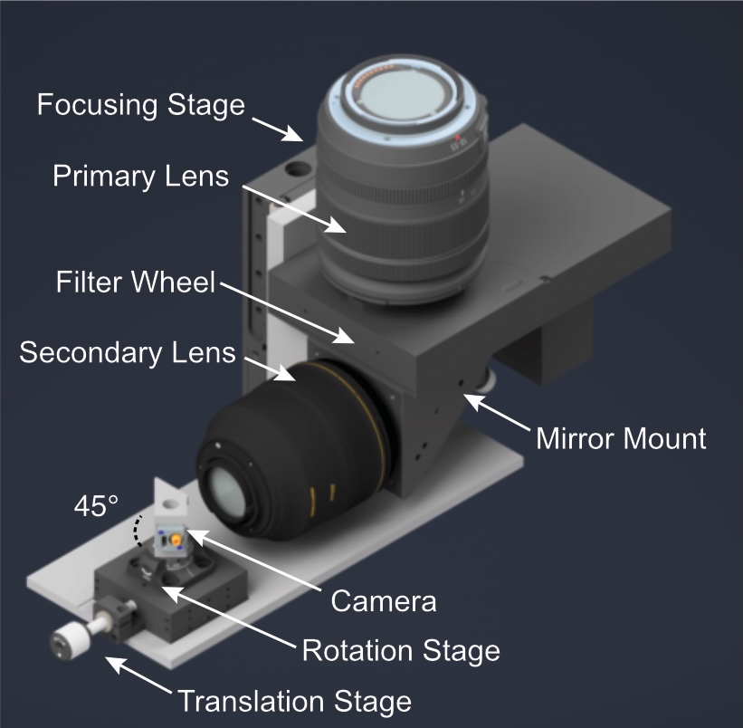
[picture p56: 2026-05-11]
docs/source/dvopm_design/Images/Detection_Assembly_Isometric.jpg

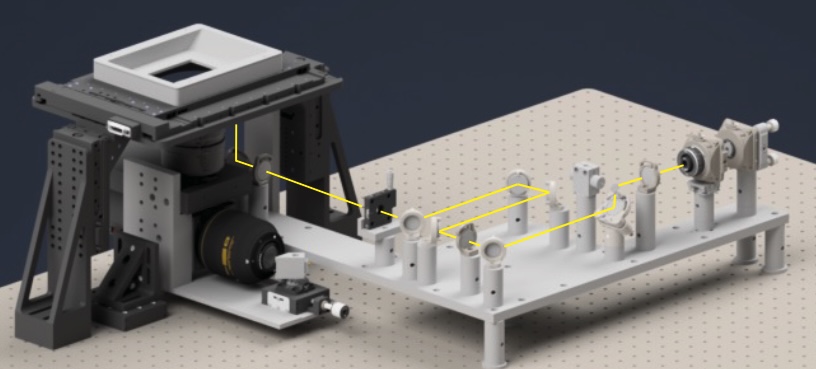
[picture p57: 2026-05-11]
docs/source/dvopm_assembly/Images/Full_Assembly.jpg

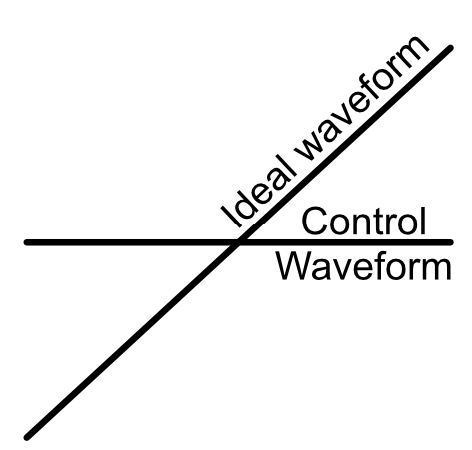
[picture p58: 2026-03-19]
docs/source/baseplate2_alignment/Images/assembly/offset.png

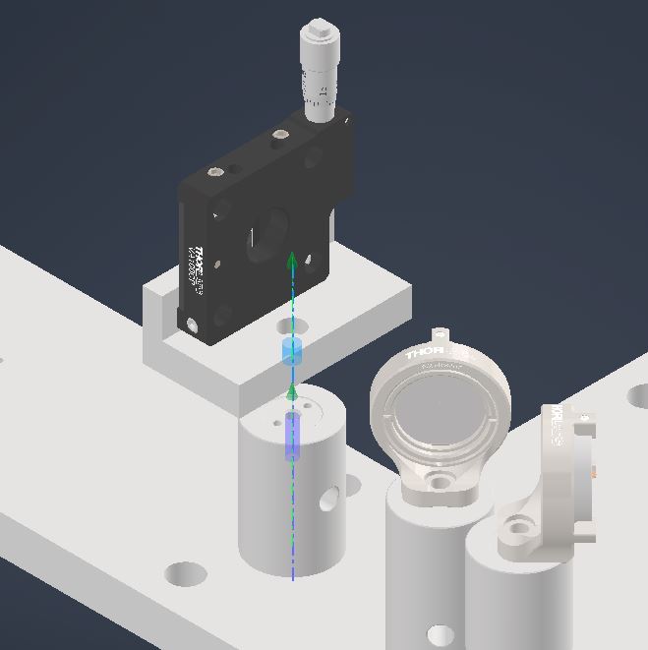
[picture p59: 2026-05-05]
docs/source/dvopm_assembly/Images/Slit_on_Baseplate.JPG

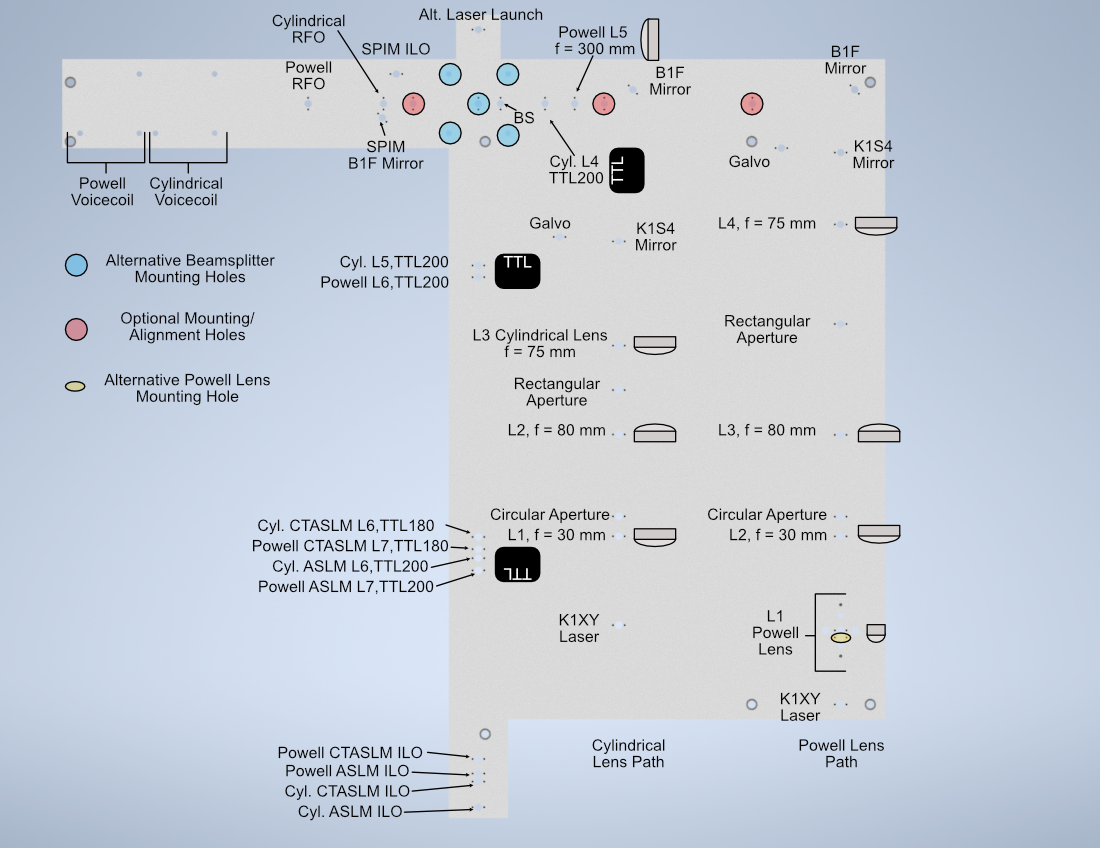
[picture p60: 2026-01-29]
docs/source/baseplate2_alignment/Images/assembly/BaseplateLabels.png

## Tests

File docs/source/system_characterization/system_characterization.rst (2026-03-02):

.. _characterization-home:

###############################
System Characterization
###############################

Beam Characterization and PSF Analysis
________________________________________

To characterize our constructed system, we first image the generated light sheet using the sample chamber transmission configuration shown below, where the illumination objective is placed directly in front of the detection objective. The image of our light sheet is shown in (a) below, where the cross-sectional profile of the light sheet is shown in (b) and reveals a z-FWHM of ~0.415 µm.

Analysis of the experimental lightsheet characteristics

    **Figure 1:** Analysis of the experimental lightsheet characteristics

To characterize the resolution of our system, we utilize 100 nm YG Fluorescent Beads (ID: 17150-10) from Polysciences Inc. The beads are first affixed onto a 5 mm coverslip using the following protocol:

.. note:: **Affixation protocol for 100 nm beads**

    1. Assemble a petri dish, coverslip, and 5 mM concentration of (3-Aminopropyl)triethoxysilane (APTS)
    2. Put 5 mm coverslip in petri dish
    3. Apply ~100 microliters of (3-Aminopropyl)triethoxysilane (APTS) on top of coverslip
    4. Allow APTS to incubate for ~10-30 minutes
    5. Wash coverslip lightly with DI water 3 times
    6. Put beads of desired dilution (typically 10^-3 or 10^-4 for a normal distribution, 10^-6 for a sparse
       distribution) onto coverslip and allow to incubate between 2-20 minutes. Longer incubation time allows for more
       beads to adhere to the coverslip
    7. Wash lightly afterwards with DI water

After affixation, the beads are imaged, and the results are shown below. The PSF of an isolated bead is shown in (a-c), where each image is a different orthogonal perspective of the bead's intensity distribution and provides insight into the resolution of our system in each orthogonal direction. We then provide Gaussian-fitted distributions of the FWHM of the fluorescent bead population across a given z-stack in (d), both before and after applying deconvolution procedures. Prior to deconvolution, the average FWHM values across the bead population were 328 nm in x, 330 nm in y, and 464 nm in z. After deconvolution with PetaKit5D, these values improved to 235.5 nm in x, 233.5 nm in y, and 350.4 nm in z.

Analysis of the experimental PSF characteristics

    **Figure 2:** Analysis of the experimental PSF characteristics

---------------

Sample Biological Images
______________________________

As a demonstration of Altair's biological imaging capabilities, we prepared and imaged mouse embryonic fibroblast
(MEF) cells, where multiple subcellular structures were stained for 4 different channels corresponding to the
excitation wavelengths of our laser source (405 nm, 488 nm, 561 nm, 638 nm). The staining protocol described in our
`initial Altair-LSFM paper <https://elifesciences.org/reviewed-preprints/106910v1>`_ was
optimized for visualization of the nucleus (DAPI, 405 nm, cyan channel), microtubules (488 nm,
gray channel), actin filaments (561 nm, gold channel), and the Golgi apparatus of the MEF cells (638 nm, magenta
channel).

A deconvolved maximum intensity projection of a distribution of MEF cells is shown below in (a) and (f), with each
individual channel displayed in (b-e) and (g-j). These results display fine nucleolar features within the
nucleus, well-defined perinuclear Golgi structures, well-resolved stress fibers in the actin channel, and individually distinct microtubules, demonstrating Altair's ability to capture high-resolution images of cytoskeletal structures.

Analysis of MEF Cells

    **Figure 3:** Analysis of MEF Cells

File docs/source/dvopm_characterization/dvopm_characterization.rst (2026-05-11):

.. _dvopmcharacterization-home:

##############################
Altair DV-OPM Characterization
##############################

To characterize the performance of the Altair DV-OPM, we evaluated the illumination train by imaging the light-sheet profile, and we quantified the system resolution using 1 µm fluorescent beads.

---------------

Beam Characterization
_____________________

To characterize the illumination beam profile, we imaged the light sheet in air while translating the camera through a series of axial positions along the propagation direction, :math:`Y'`. A fixed lateral region near the center of the sheet was selected so that the thickness measurement was obtained from the same representative region at each axial position.

For each axial plane, the background-corrected intensity profile along the sheet-thickness direction, :math:`Z'`, was extracted and fit with a Gaussian function. The fitted Gaussian standard deviation, :math:`\sigma`, was converted to full width at half maximum (FWHM) using

.. math::

    \mathrm{FWHM} = 2\sqrt{2\ln 2}\,\sigma \approx 2.355\sigma

after applying the camera pixel size calibration.

The FWHM was then converted to the Gaussian beam waist, :math:`w`, using

.. math::

    w = \frac{\mathrm{FWHM}}{\sqrt{2\ln 2}}

where :math:`w` corresponds to the :math:`1/e^2` intensity radius of the beam.

The best-focus plane was defined as the axial position corresponding to the minimum FWHM. At this plane, we measured a minimum FWHM of :math:`17.1~\mu\mathrm{m}`, corresponding to a beam waist of :math:`w_0 = 14.53~\mu\mathrm{m}`.

The usable axial extent of the light sheet was determined experimentally from the measured waist profile as the axial range over which

.. math::

    w(Y') \leq \sqrt{2}\,w_0

yielding a usable distance of approximately :math:`2.00~\mathrm{mm}`.

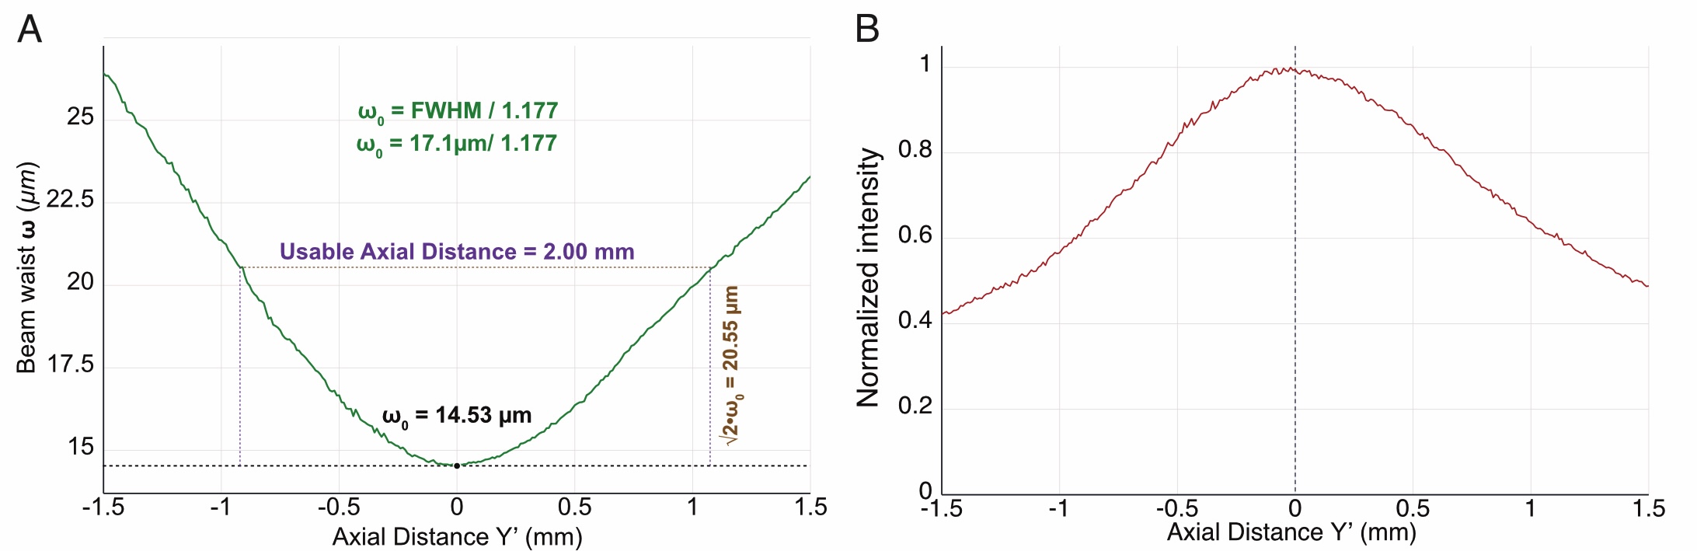
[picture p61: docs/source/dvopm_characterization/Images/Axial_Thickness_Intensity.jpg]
Sheet profile characterization.


    **Figure 1:** Characterization of the light-sheet profile in air along the axial direction.

At the best-focus plane, we additionally characterized the spatial distribution of the sheet. A representative image was used to visualize the light-sheet morphology and its lateral extent along :math:`X'`. The normalized background-corrected intensity profile along :math:`Z'` was used to quantify the sheet thickness, while the lateral intensity profile along :math:`X'` was calculated by summing the background-corrected intensity along :math:`Z'` at each lateral position. This provided a measure of the illumination uniformity across the approximately :math:`6.5~\mathrm{mm}` lateral extent of the sheet.

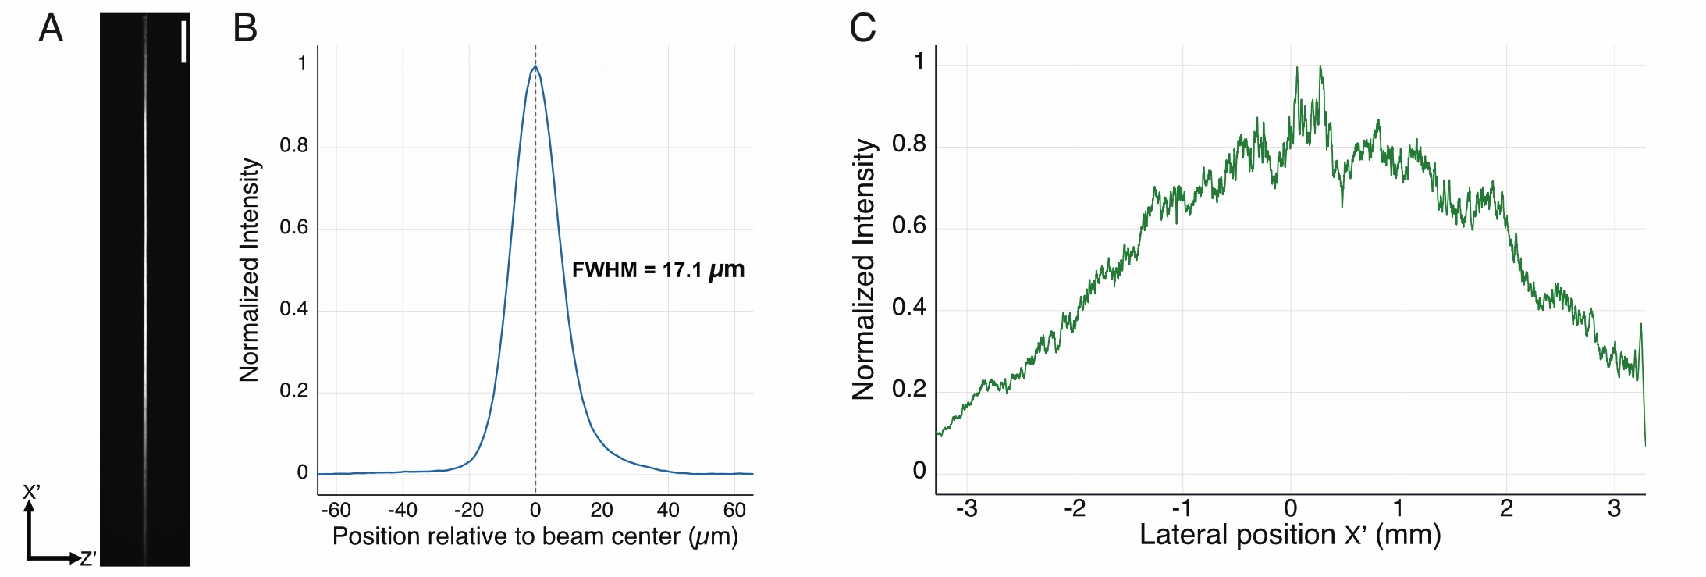
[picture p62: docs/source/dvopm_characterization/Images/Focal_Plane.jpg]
Sheet profile characterization at focal plane.


    **Figure 2:** Characterization of the light-sheet profile in air at the best-focus plane. A. Camera image of the light sheet at the best-focus plane. B. Normalized intensity profile along the sheet-thickness direction, :math:`Z'`. C. Normalized intensity profile along the lateral direction, :math:`X'`.

Resolution Quantification
_________________________

To quantify the imaging resolution of the system, we imaged 1 µm fluorescent beads embedded in agarose.

Beads were imaged at different axial positions along the propagation direction, :math:`Y'`, and the FWHM of the bead images was measured along the lateral and axial directions to quantify system resolution across the field of view.

To prepare the fluorescent bead sample, 1 µm YG fluorescent nanospheres were diluted 1:1000 in deionized water and sonicated for 3 minutes to minimize aggregation. The resulting solution was subsequently mixed at a 1:100 dilution ratio with 2% low-melting-point agarose for volumetric imaging.

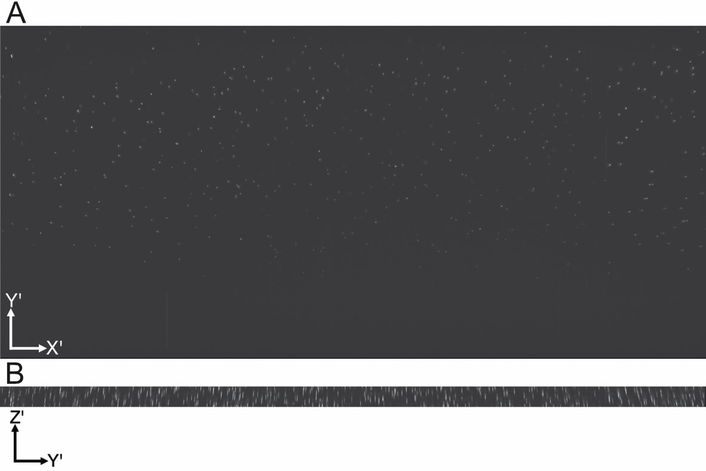
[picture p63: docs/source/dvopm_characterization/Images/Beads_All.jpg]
Bead characterization.


    **Figure 3:** Images of 1 µm fluorescent beads embedded in agarose and imaged with the Altair DV-OPM. A. Maximum-intensity projection of the bead sample in the :math:`X'Y'` plane. B. Maximum-intensity projection of the bead sample in the :math:`X'Z'` plane.

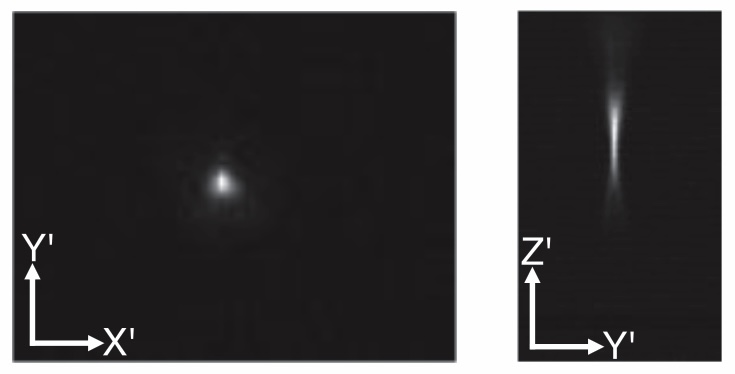
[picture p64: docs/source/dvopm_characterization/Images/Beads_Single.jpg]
Bead characterization profiles.


    **Figure 4:** Zoomed-in image of a single fluorescent bead shown in the :math:`X'Y'` and :math:`X'Z'` planes.

We measured the full width at half maximum (FWHM) from images of 1 µm fluorescent beads (:math:`n = 302` beads). The measurements were grouped into eight grids based on lateral position across the field of view, and the median FWHM values for each section are reported in micrometers along the :math:`X'`, :math:`Y'`, and :math:`Z'` directions.

Bead characterization profiles.

    **Figure 5:** Median FWHM values measured from images of 1 µm fluorescent beads, grouped by lateral position across the field of view.

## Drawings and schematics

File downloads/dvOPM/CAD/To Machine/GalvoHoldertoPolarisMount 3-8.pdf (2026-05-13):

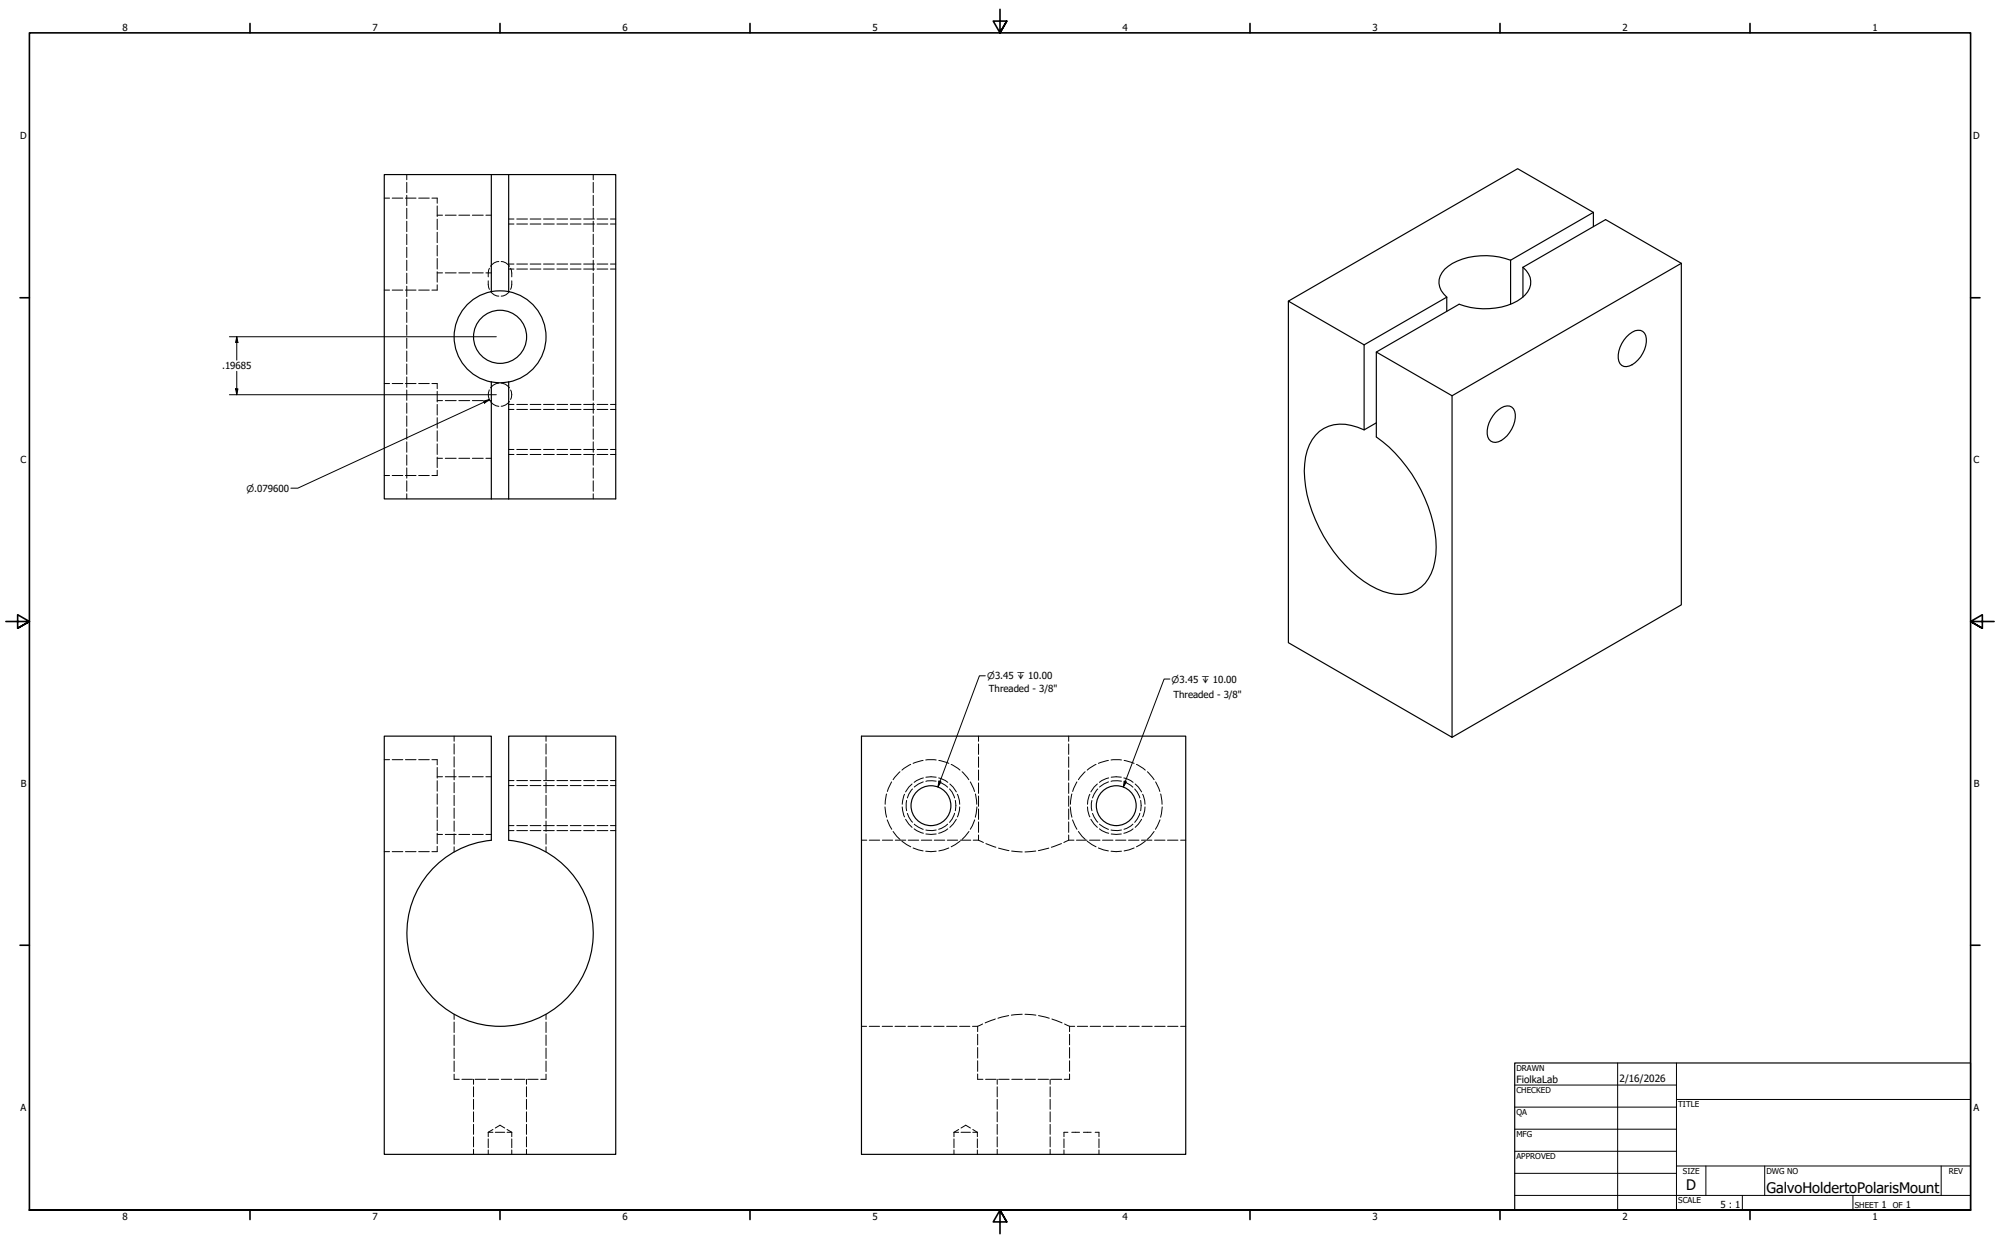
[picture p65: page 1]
Threaded - 3/8"

DRAWN FiolkaLab | 2/16/2026

CHECKED

MFG

APPROVED

SIZE D | DWG NO GalvoHoldertoPolarisMount | REV

SCALE 5 : 1 | | SHEET 1 OF 1

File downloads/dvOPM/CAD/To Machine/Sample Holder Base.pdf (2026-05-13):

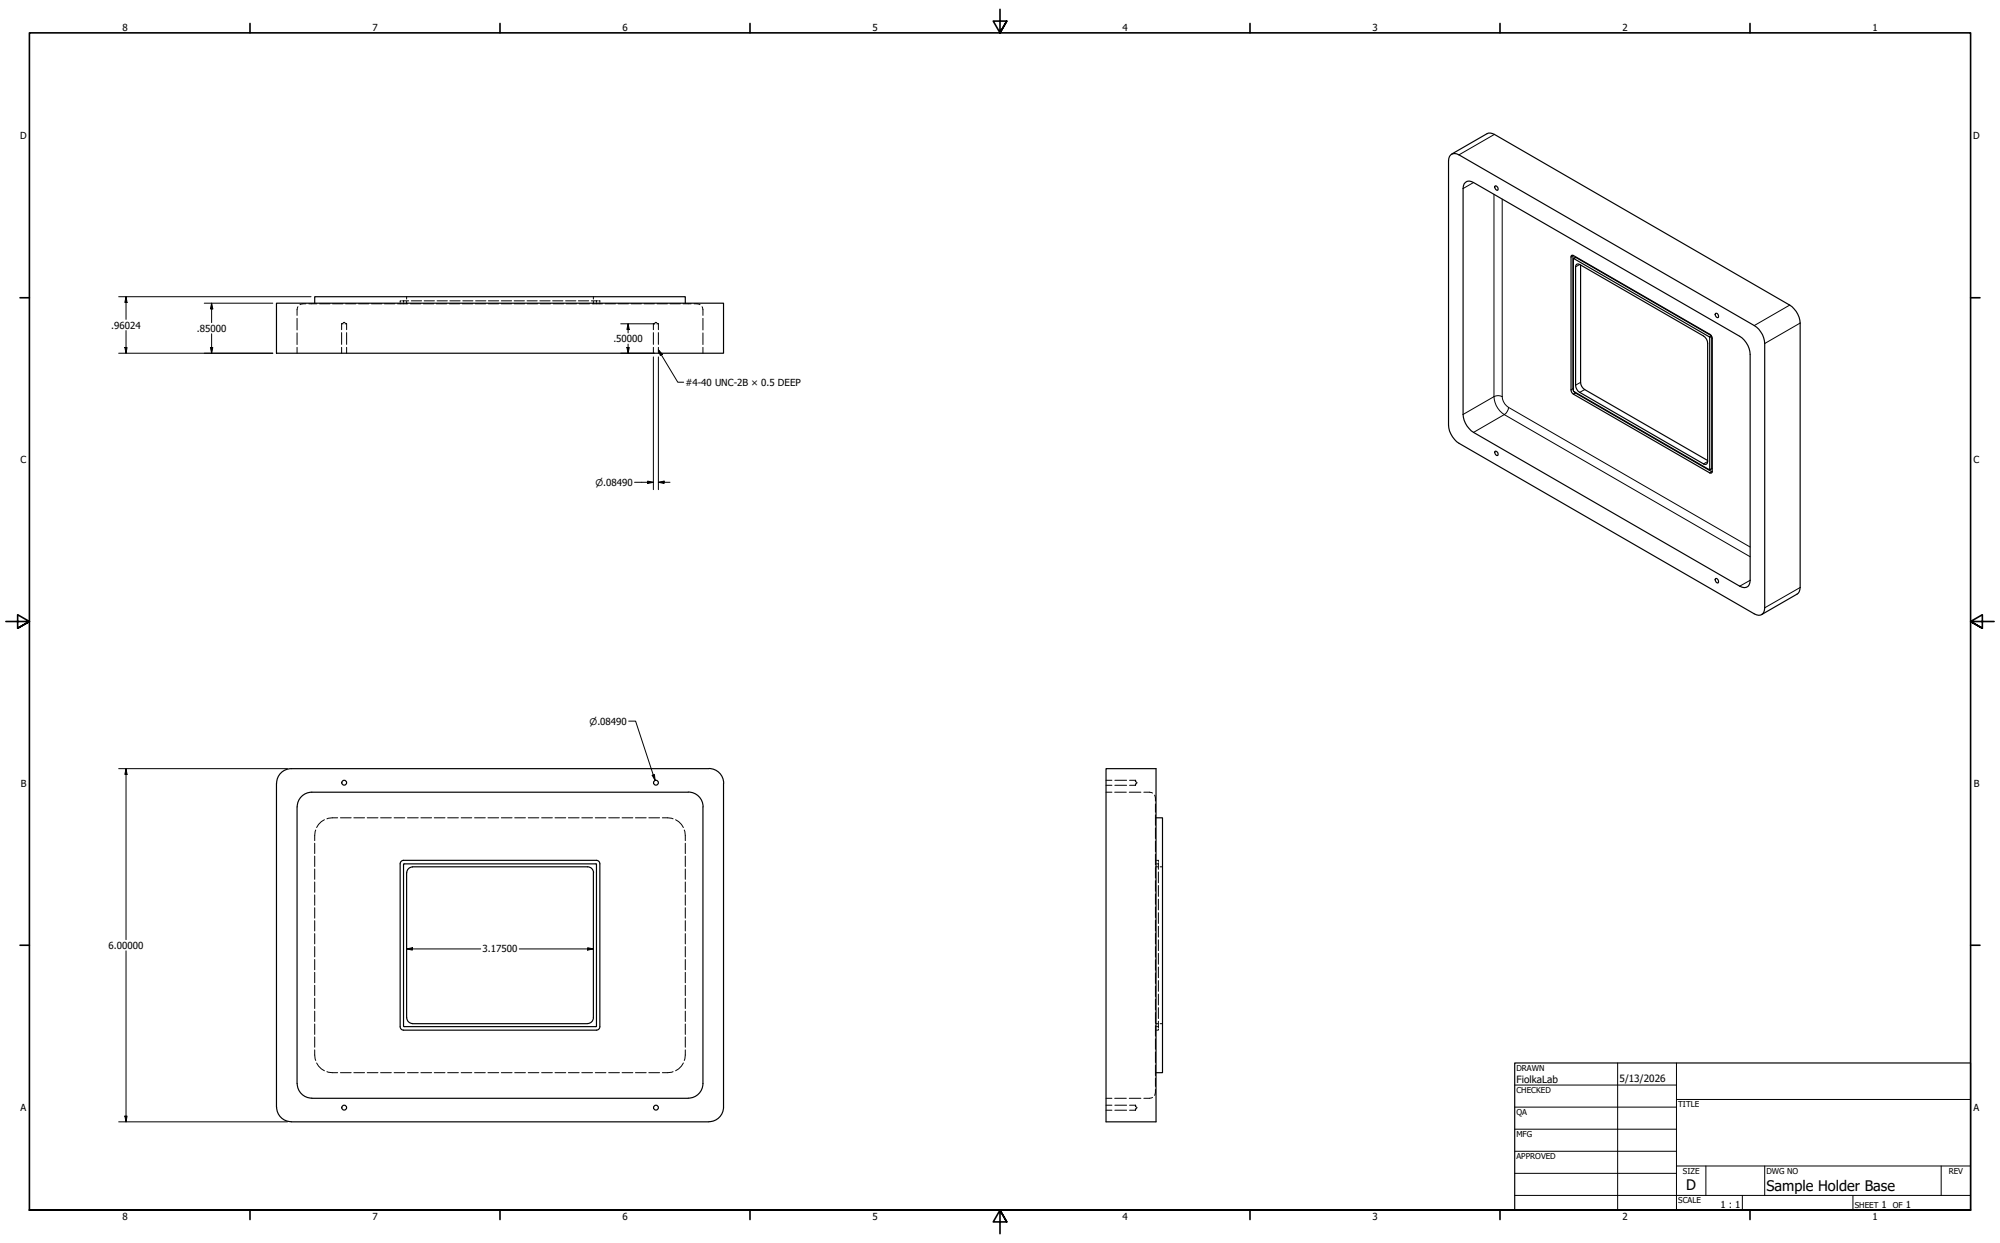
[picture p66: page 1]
#4-40 UNC-2B × 0.5 DEEP

DRAWN FiolkaLab | 5/13/2026

CHECKED

MFG

APPROVED

SIZE D | DWG NO Sample Holder Base | REV

SCALE 1 : 1 | | SHEET 1 OF 1

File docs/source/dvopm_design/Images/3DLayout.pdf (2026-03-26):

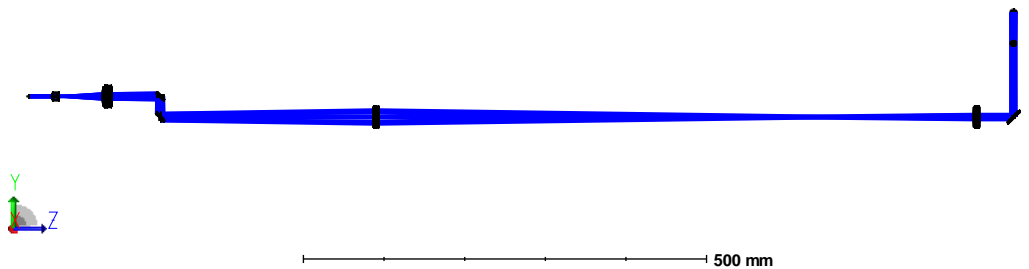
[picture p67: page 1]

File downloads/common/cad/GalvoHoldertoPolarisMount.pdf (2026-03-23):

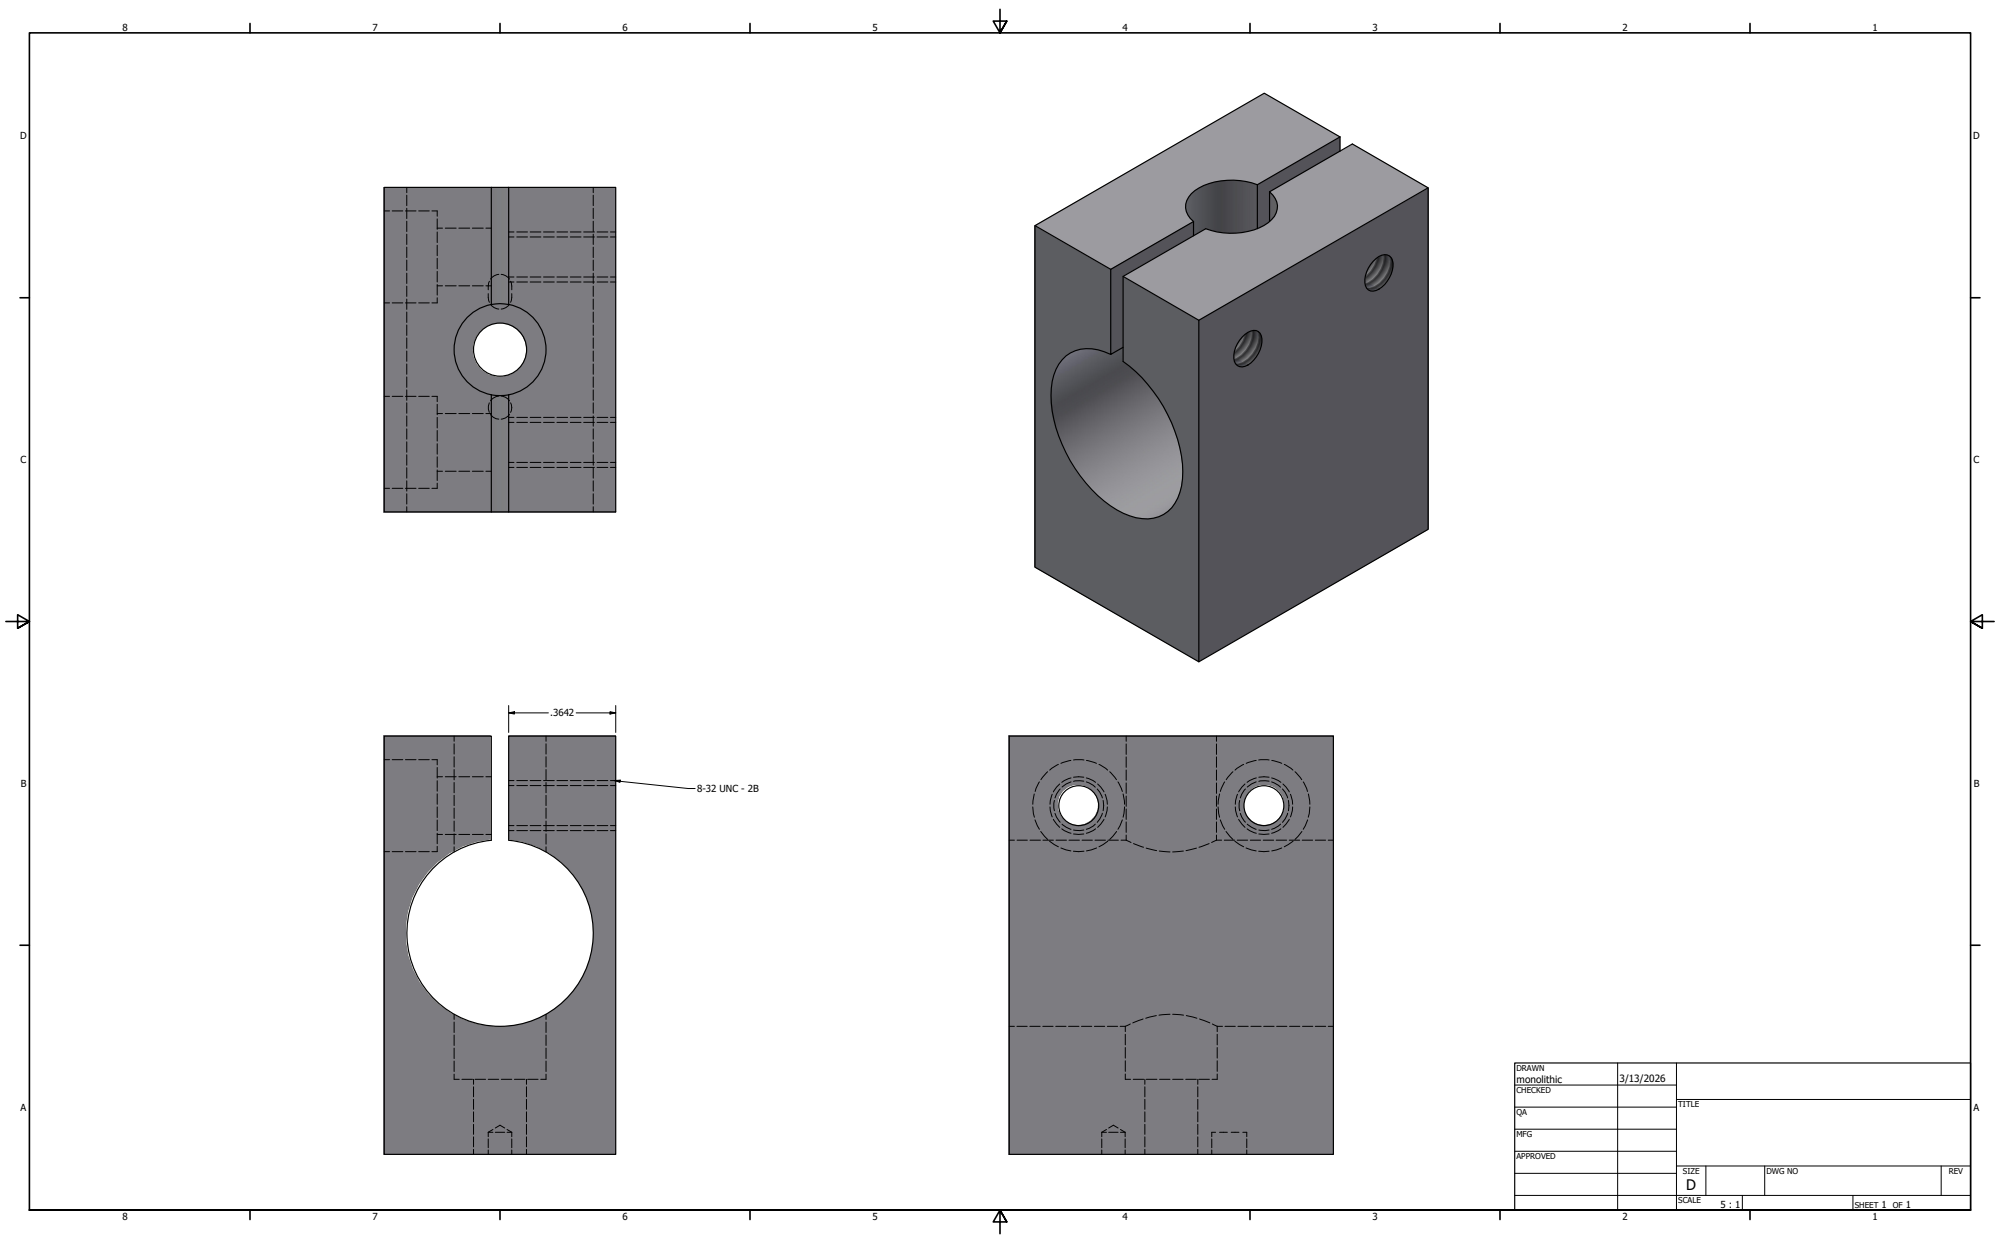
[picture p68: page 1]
8-32 UNC - 2B

DRAWN monolithic | 3/13/2026

CHECKED

MFG

APPROVED

SIZE D | DWG NO | REV

SCALE 5 : 1 | | SHEET 1 OF 1

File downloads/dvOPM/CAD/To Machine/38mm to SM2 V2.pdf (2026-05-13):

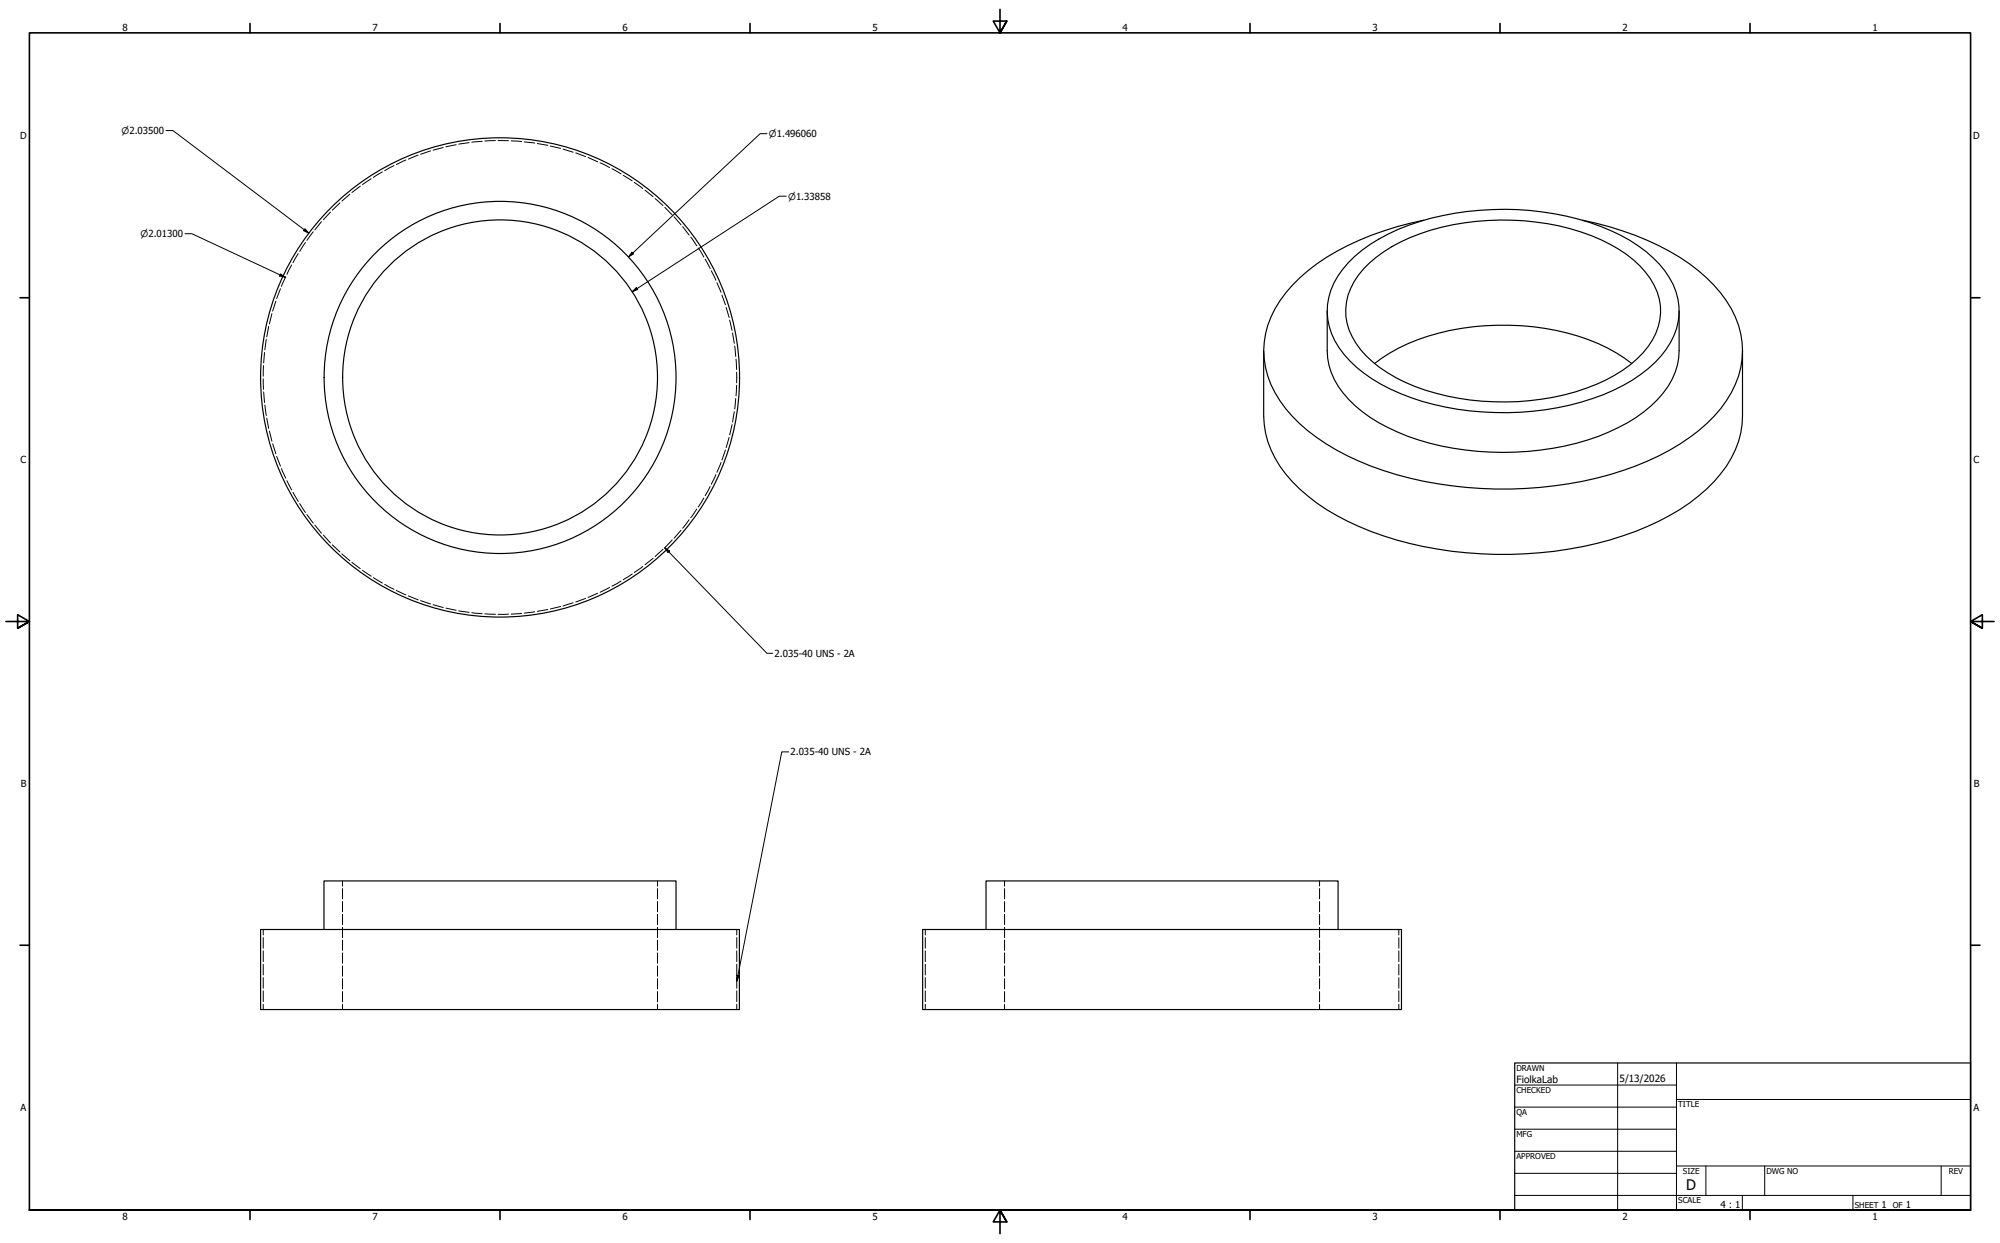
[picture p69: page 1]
2.035-40 UNS - 2A

DRAWN FiolkaLab | 5/13/2026

CHECKED

MFG

APPROVED

SIZE D | DWG NO | REV

SCALE 4 : 1 | | SHEET 1 OF 1

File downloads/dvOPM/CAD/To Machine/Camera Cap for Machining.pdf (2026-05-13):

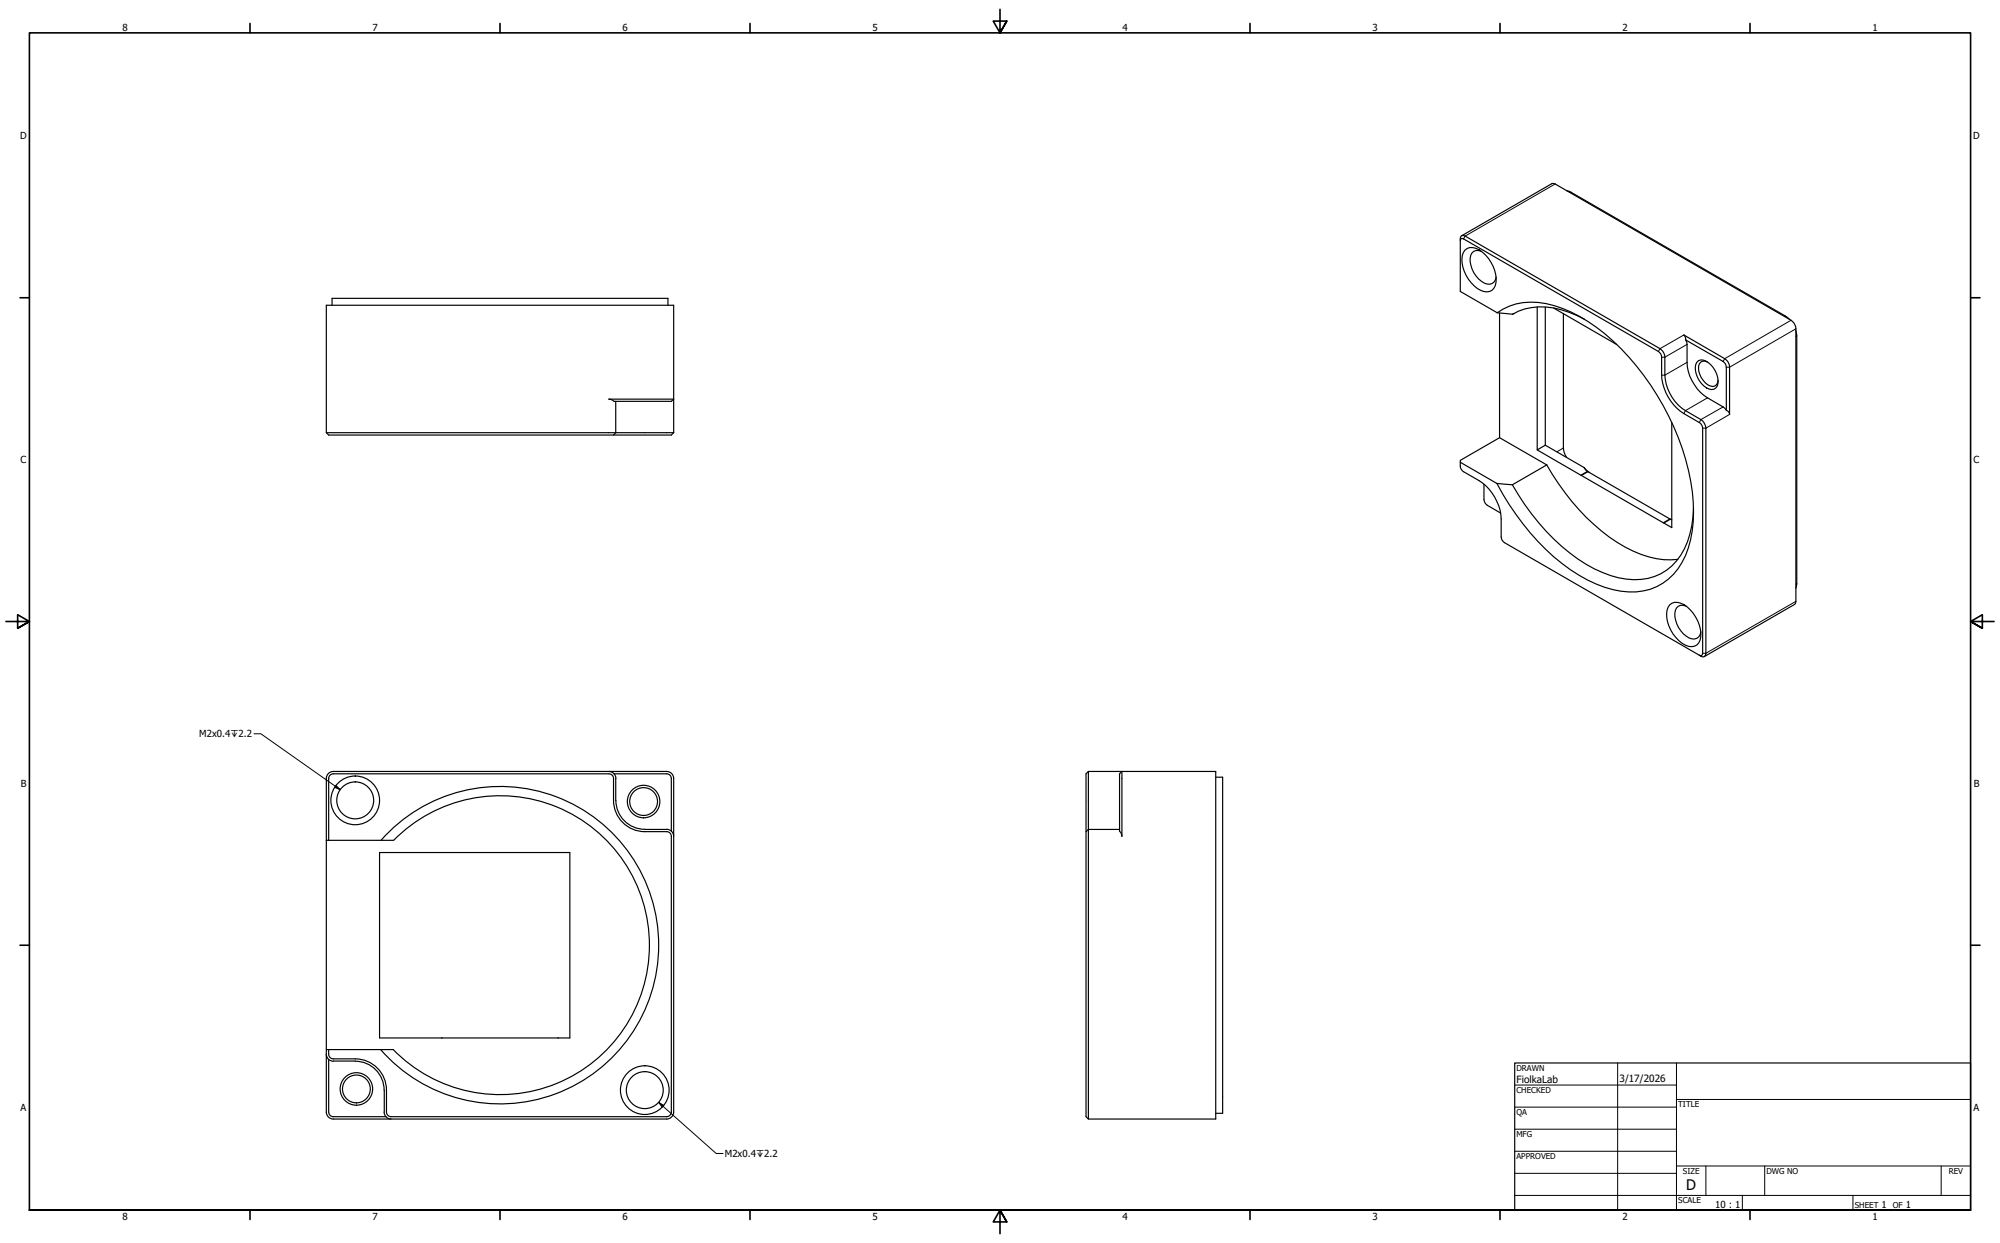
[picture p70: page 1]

DRAWN FiolkaLab | 3/17/2026

CHECKED

MFG

APPROVED

SIZE D | DWG NO | REV

SCALE 10 : 1 | | SHEET 1 OF 1

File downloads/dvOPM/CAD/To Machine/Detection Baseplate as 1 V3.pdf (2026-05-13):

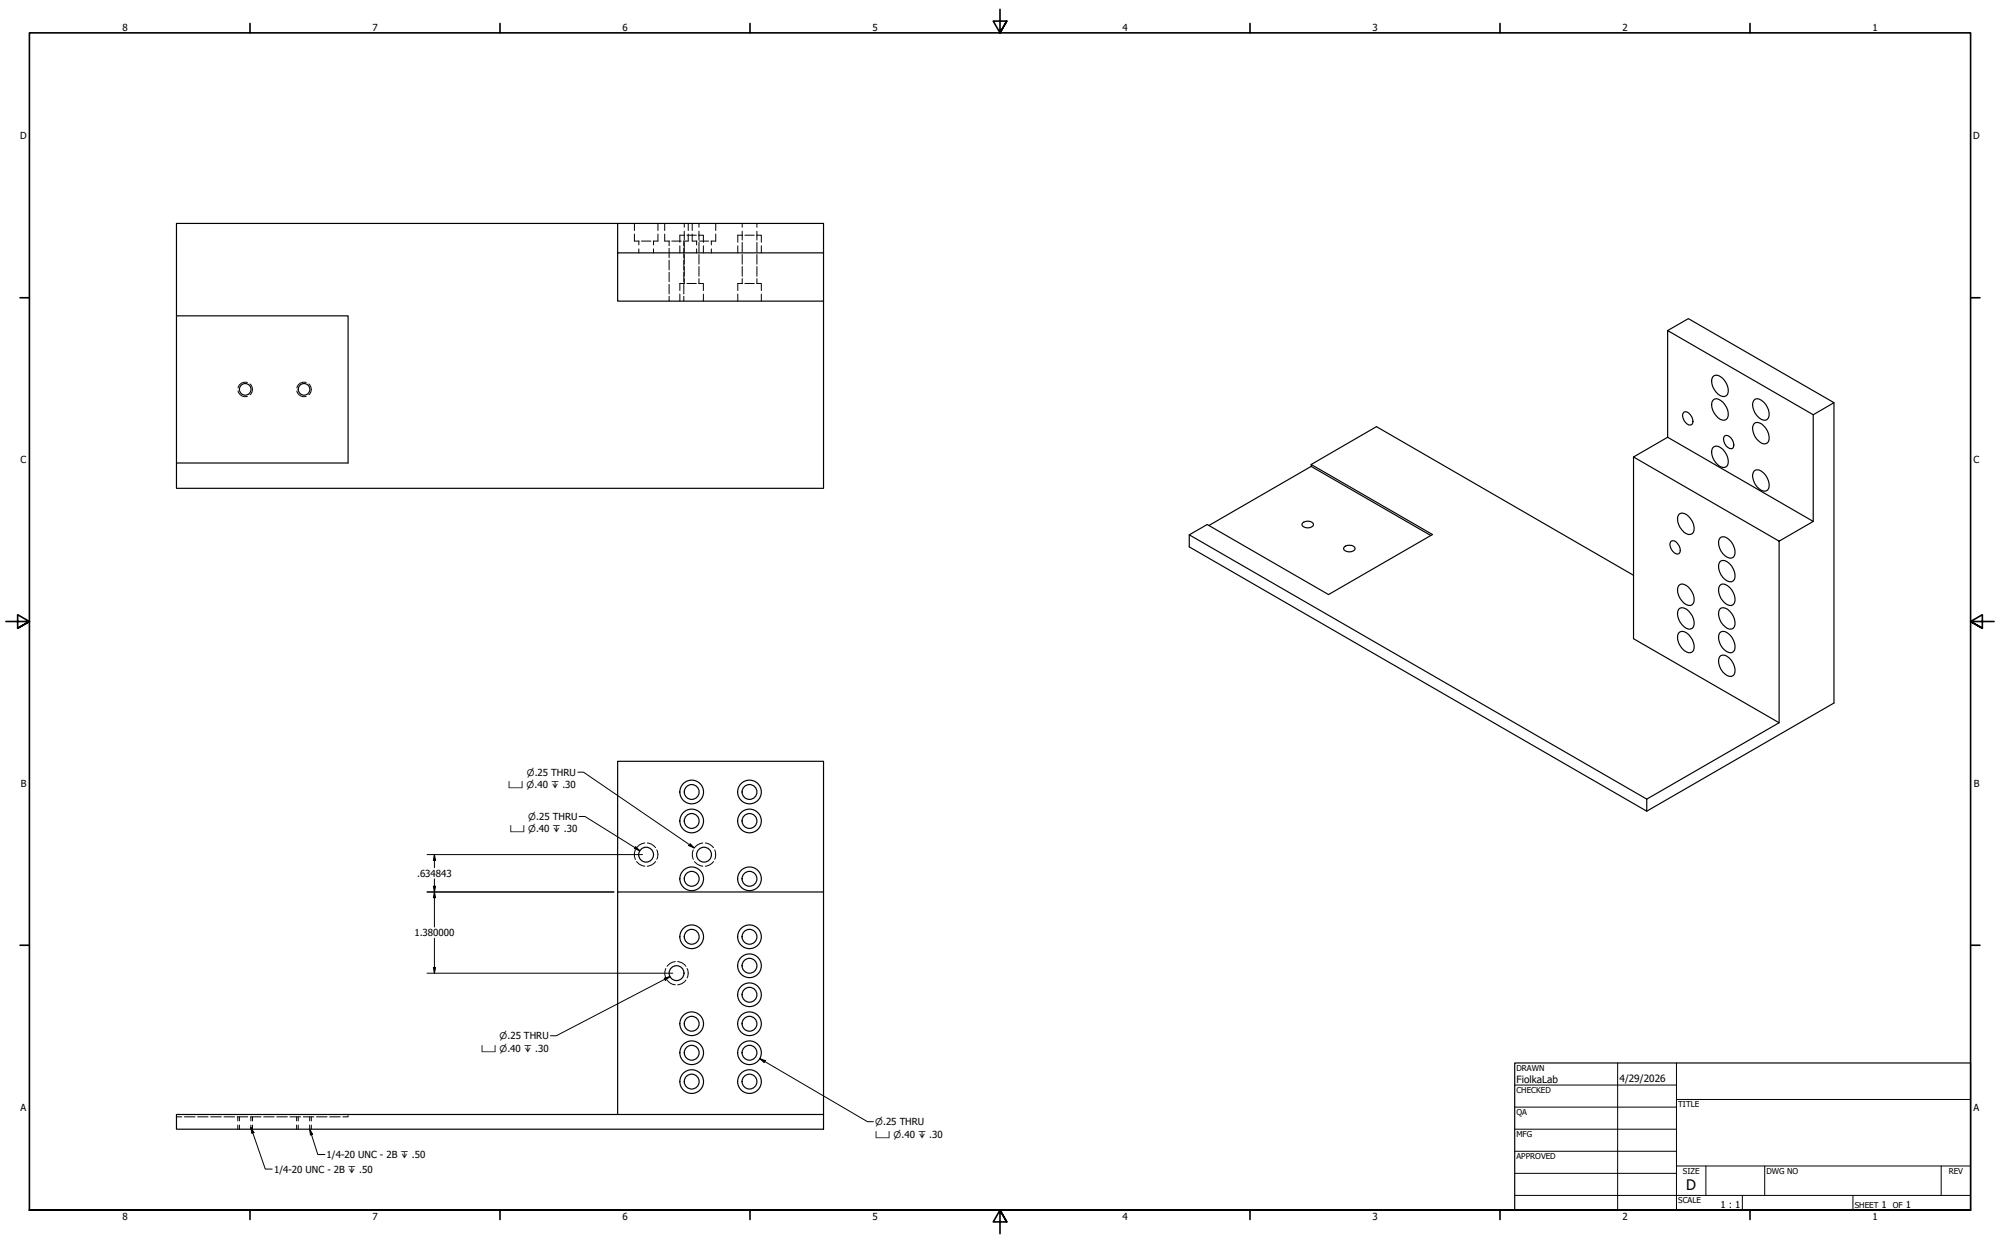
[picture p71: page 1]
1/4-20 UNC - 2B ↧ .50; ⌀.25 THRU ⌴ ⌀.40 ↧ .30

DRAWN FiolkaLab | 4/29/2026

CHECKED

SIZE D | DWG NO | REV

SCALE 1 : 1 | | SHEET 1 OF 1

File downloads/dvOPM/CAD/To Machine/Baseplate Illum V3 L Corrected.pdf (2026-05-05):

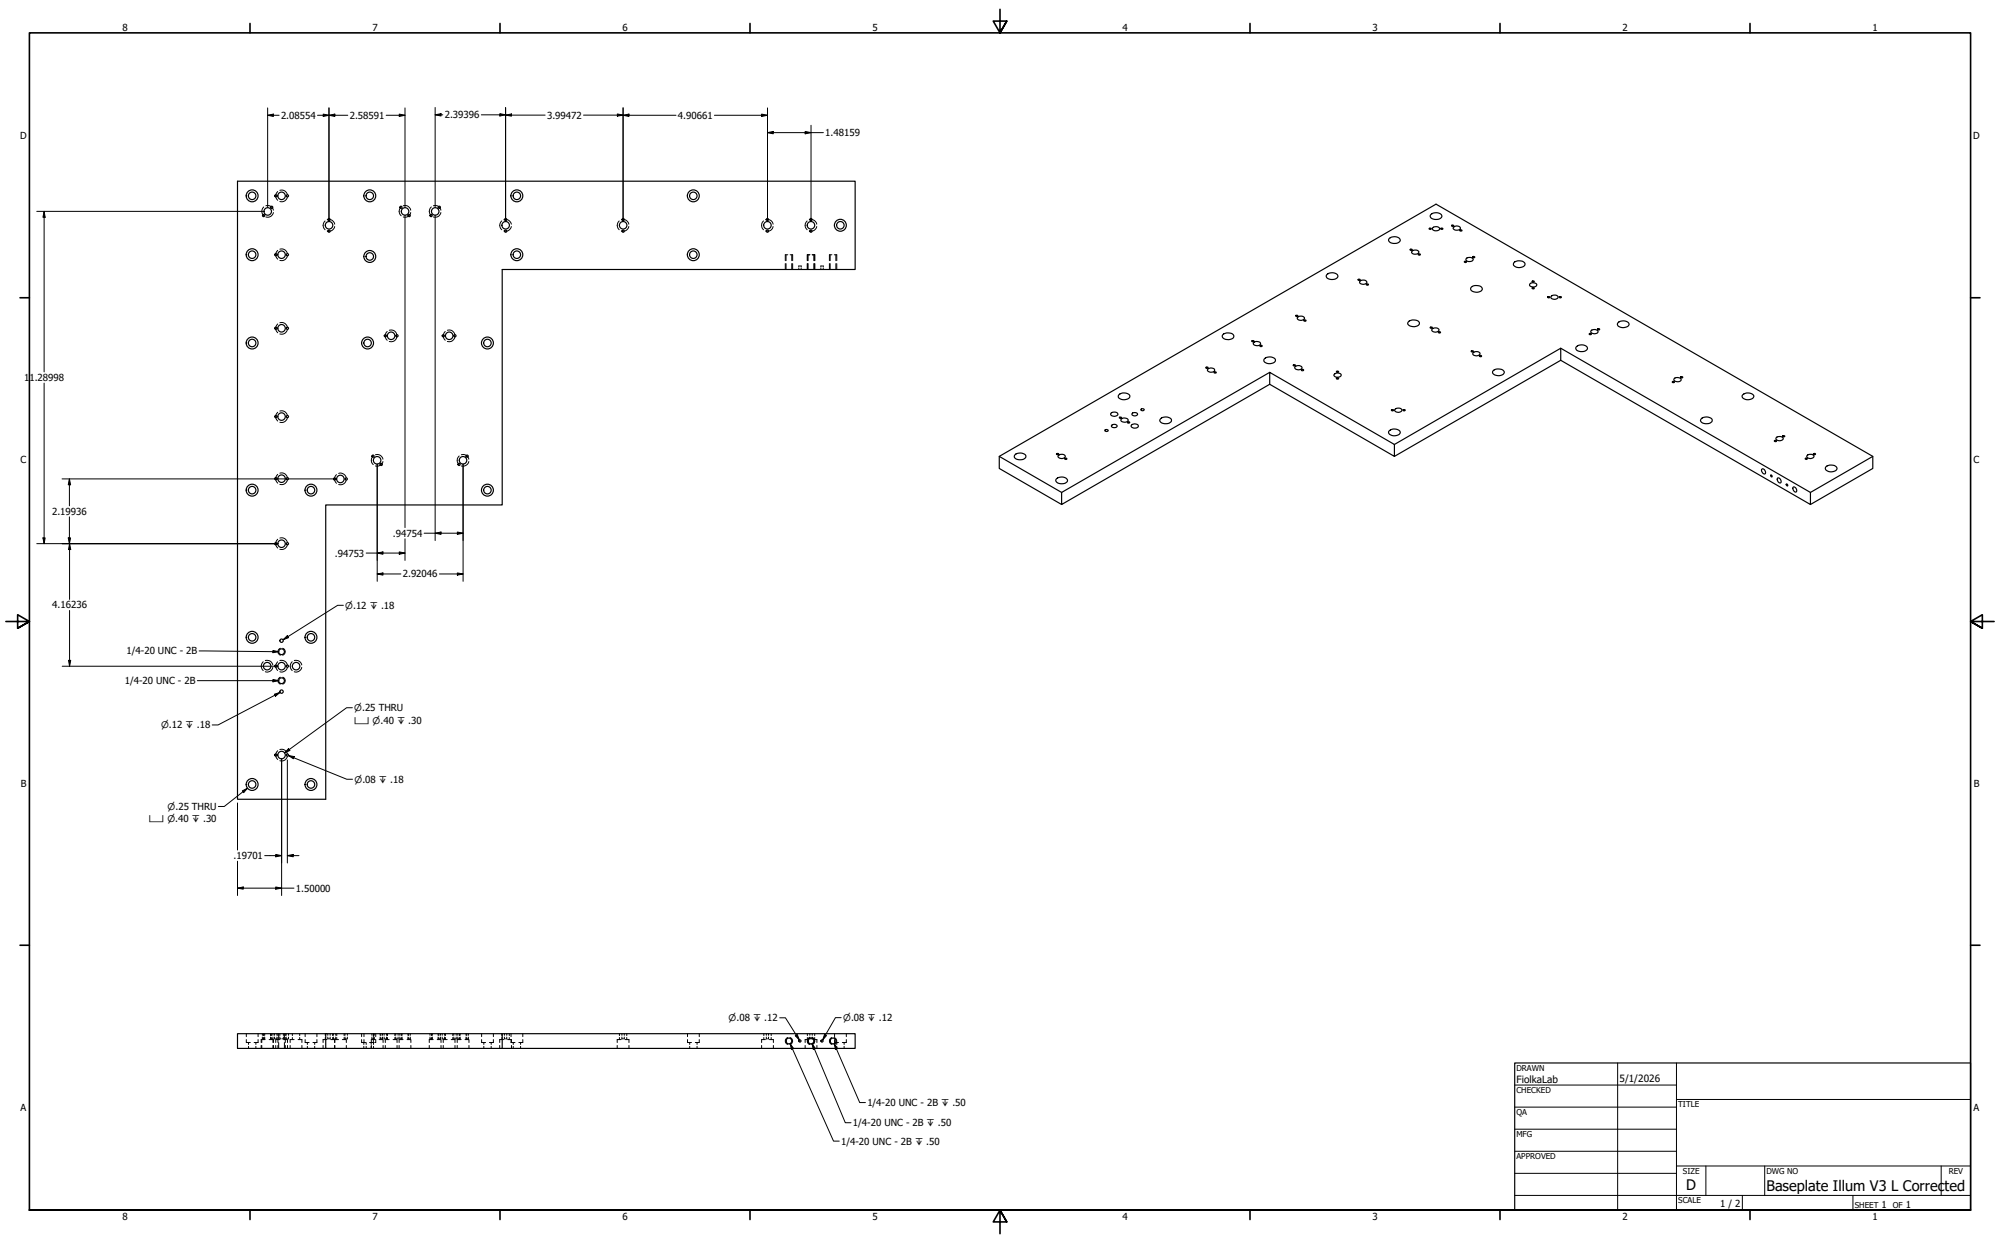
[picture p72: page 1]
1/4-20 UNC - 2B ↧ .50; ⌀.25 THRU ⌴ ⌀.40 ↧ .30; 1/4-20 UNC - 2B

DRAWN FiolkaLab | 5/1/2026

CHECKED

MFG

APPROVED

SIZE D | DWG NO Baseplate Illum V3 L Corrected | REV

SCALE 1 / 2 | | SHEET 1 OF 1

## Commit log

2025-09-08 added components
    [Atlair_Powell_SPIM_ASLM_CTASLM_Baseplate_V2.ipt, Atlair_Powell_SPIM_ASLM_CTASLM_Baseplate_V2.stp, BeamsplitterMounttoPolarisPinAdapterV3.ipt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]
2025-09-17 added 45 degree mirror post
    [45DegreeMirrorPost_0p75in.ipt, 45DegreeMirrorPost_0p75in.stl, 45DegreeMirrorPost_0p75in.stp]
2025-12-26 Update links for Powell lenses in baseplate2.rst. Links were broken, causing test to fail.
2026-01-07 Expand computer hardware docs with power management guide
    Added detailed instructions for configuring Windows and BIOS/UEFI power management settings to optimize performance and determinism for scientific imaging computers. The documentation now covers reco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
2026-01-29 Fleshed out new powell lens assembly section
2026-03-02 Add eLife publication and benchmark details
    Update README.md and docs/source/index.rst to include eLife article and DOI badges, a publication citation, and a brief summary of Altair-LSFM performance. Clarify wording around microscope goals and replace previous resolution claim with measured FWHM benchmarks (328/330/464 nm before deconvolution and ~235/233/350 nm after deconvolution across a 266 µm FOV). Minor phrasing tweaks to emphasize high-performance, easy-to-build design and link to the published article.
2026-03-02 Added assembly files
    [AC254-030-A-Step.ipt, AC254-030-OnPost.iam, AC254-075-A-Step.ipt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]
2026-03-19 TG16 image, voice coil wiring, waveform parameters pt. 1
2026-03-23 Added in placeholder sections for Muaaz's DVOPM build
    [GalvoHoldertoPolarisMount.0002.ipt, GalvoHoldertoPolarisMount.dwg, GalvoHoldertoPolarisMount.ipt]
2026-04-28 Fix typos and captions in dvopm_assembly docs
    Update dvopm_assembly.rst and related images: corrected spelling and grammar (e.g. "refernce" -> "reference", "paralell" -> "parallel"), removed duplicated/extra lines, and standardized figure metadata by converting hand-written "**Figure:**" notes to Sphinx :caption: directives. Two image files were also updated (binary changes). These changes improve clarity of the alignment and lens setup instructions and ensure consistent caption rendering in the documentation.
2026-04-28 Revise DV-OPM detection assembly docs
    Rewrite and reorganize the detection-train documentation for the DV-OPM baseplate: clarify the detection assembly description, lens choices and limitations (pixel pitch, non-telecentricity), and Zema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
2026-04-30 CAD Files dvOPM
    [38mm to SM2 V2.ipt, 38mm to SM2.stp, 52mm to 52mm.ipt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]
2026-05-05 Added Simulation Files for ASLM/CTASLM Baseplate
    [CollagenSampleHolder.ipt, CollagenSampleHolder.stl]
2026-05-05 dvOPM Assembly Instructions
    [Baseplate Illum V3 L Corrected.stp]
2026-05-05 dvOPM Assembly
2026-05-13 Add Sample Holder File
    [38mm to SM2 V2.stp, 38mm to SM2.stp, Baseplate as 1 V3 Corrected.stp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]
2026-05-13 Edit schematic
    [LNR25MtoPolarisAdapter.stp]
2026-06-28 feat: add blender optics simulation toolkit
    Create a reusable Blender simulation area under simulations/blender, including a local AGENTS.md and README so future educational optics videos share the same conventions.
    Add the altair_blender helper package for import-safe scene setup, optical materials, geometry primitives, camera framing, beam and return-spot animation, and paraxial back-reflection math.
    Add the first achromat back-reflection scene for a 561 nm, 1 mm collimated beam passing through a 1 mm business-card aperture onto an AC254-100-A-ML-style achromat. The animated scene starts misaligned and iteratively brings the two return reflections back onto the aperture.
    Add focused pyt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
2026-06-28 feat: add achromat render movie workflow
    Add a reusable shell workflow for the achromat back-reflection scene that creates the generated .blend file, renders both Wide Setup Camera and Card Close-Up Camera PNG sequences, stacks the two view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
    The script supports dry-run output for quick inspection plus FRAME_START, FRAME_END, RESOLUTION_X, RESOLUTION_Y, FPS, CRF, BLENDER_BIN, and FFMPEG_BIN overrides for smoke renders and local runtime di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
    Document the movie workflow in simulations/blender/README.md, update simulations/blender/AGENTS.md with the render-script convention, and ignore the root out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
2026-06-28 feat: improve achromat ray-tracing fidelity
    Add source-backed AC254-100-A and LMR1/M prescriptions, including mounted-lens dimensions, AC-series surface radii, element thicknesses, and mount dimensions used by the scene.
    Replace the simple cylinder achromat with a two-element cemented doublet mesh, add an LMR1-style fixed mount, separate glass/coating/material handling, soft area lighting, and shadow-capable scene defaults.
    Replace the hand-tuned two-spot approximation in the scene with geometric ray-bundle reflection summaries from selected spherical surfaces. The two visible return spots now derive their positions and different diameters from surface curvature and the current tilt/decent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
2026-06-28 feat: add cinematic achromat render workflow
    Add reusable preview/final render presets, with final mode selecting Cycles through direct engine assignment so Blender 5.1 runtimes that expose a stale engine enum still use the requested renderer.
    Add a slow hero camera, minimal in-scene labels, refined studio lighting/materials, and a flat backdrop to make the achromat alignment scene read as a polished educational video rather than a one-off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
    Extend the render script so it preserves the existing wide, card close-up, and stacked outputs while adding hero PNG/MP4 output, --preview/--final flags, robust argument parsing, and rendering from t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
    Update the Blender R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
2026-06-29 Codex/blender render hpc visuals (#8)
    * Improve Blender render workflow and optics scene
    Add a Linux/HPC render wrapper that loads the ffmpeg module, points at the /project Blender install, and defaults Cycles to CUDA. Wire CYCLES_DEVICE through scene creation and per-camera rendering so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
    Make the achromat back-reflection animation more legible in the wide movie by adding display-only alignment exaggeration and a subtle animated wide-camera push while leaving the underlying optics cal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
    Brighten the scene by replacing the black studio table/backdrop with a neutral gray environment, a brushed stainless optical table, and shallow dar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
2026-06-29 docs: add achromat back-reflection movie
    Add the rendered stacked achromat back-reflection MP4 as a tracked documentation static asset so it is available to the Sphinx HTML build.
    Embed the movie in the baseplate2 alignment instructions near the back-reflection alignment step, alongside the existing pinhole-card guidance.
    Keep generated render output and raw frame sequences ignored; only the curated documentation MP4 is tracked.
    Verification: sphinx-build -b html docs/source docs/build/html via uvx with docs extras; pytest tests/test_blender_import_contracts.py tests/test_achromat_scene_contract.py tests/test_blender_render_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
2026-06-29 Switch from unittest to pytest and add linting tools
    Replace unittest with pytest for test discovery and execution in the test_docs workflow. Add pytest to docs dependencies in pyproject.toml. Add typos and vale linting tools to docs extras. Clean up trailing whitespace in documentation files and remove an invalid reference link from computer.rst.
2026-07-01 [codex] Add and refine walking-beam alignment simulation (#10)
    * Add walking beam alignment simulation
    * Improve walking beam physical layout
    Increase the Iris 1 to Iris 2 spacing to five table holes, flip both mirror mount yaw defaults by 180 degrees for the visible setup, and route the rendered beam through explicit mirror-surface points instead of mount centers. The scene contract now pins these physical layout expectations.
    * Refine walking beam hardware supports
    Add explicit visual support controls for post-mounted irises and kinematic mirror mounts. Shorten iris supports below the aperture, offset mirror supports behind the frame, add rear support brackets, and attach adjuster shaf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
